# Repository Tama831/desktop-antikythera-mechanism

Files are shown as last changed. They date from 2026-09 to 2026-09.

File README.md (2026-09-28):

# Desktop Antikythera Mechanism — 巡る天の心臓 / Meguru

> A desktop-size descendant of the Antikythera mechanism, with a three-axis tourbillon heart.

2000年前の天文計算機アンティキティラ機構の子孫に、月の秤動・サロス周期・傾く天球、そして
**18.6年の交点歳差 (誤差 +0.18%)** を仕込んだ真・3軸機構。すべて歯数の整数比から。
家庭医 たま × Claude (AI) の共作 (2026-07〜08)。

A three-axis tourbillon descendant of the Antikythera mechanism: lunar libration, Saros cycle,
tilted ecliptic sphere, and the 18.6-year lunar nodal precession (+0.18% error) — all from
integer gear ratios. Co-created by a family physician and Claude (AI).

**▶ 解説サイト / Site**: https://tama831.github.io/desktop-antikythera-mechanism/

## 中身 / Contents
- `meguru_v6.scad` — 全パラメトリック設計 (OpenSCAD)。collide/bite/シェル/engage の検証 PART 込み
- `stl/` — 印刷部品 38ファイル・48個 (Phrozen Sonic Mini 4K 想定・タフレジン推奨)
- `BOM.md` — 部品表・輪列仕様・組立手順
- `mesh-verification.md` — 修正45件の検証履歴 (検査の四点測量の記録)
- `verify_v7.sh` / `stl_solid.py` / `stl_vol.py` — 全数検証の台本 (OpenSCAD Manifold バックエンド・数分)
- `pairwise.sh` / `pairwise.scad` — 総当たり (20剛体・手回し/モーターの2モード)・重力 (支えの有無)・付け替え経路 (モーターの揺りかごを前へ滑らせる掃引) の検査 / `physics_check.py` — トルク・浮き・倒れにくさ (`--tip`) の机上計算
- `stands.scad` — 置き方の触れる比較で選ばなかった案 (A 三つ足 / C 台座ドラム) の記録
- `docs/` — 機構解説・組み立ての書・印刷計画書・隣接台帳 (GitHub Pages)

## 状態 / Status
> ✅ **置き方とモーターの揺りかごまで設計・検証済み (v0.7.3, 2026-09-28)**: アーミラリーの三脚+足輪で立ち (倒れ始める傾き 56°)、モーターは揺りかごを前から滑り込ませてノブの下面の横溝に軸を差す (工具なしで手回しと付け替え)。物理チェックで見つかった組み上がらない箇所も修正済み (v0.7.2)。**実機は未印刷**です。
> Designed and verified through v0.7.3: an armillary-style tripod with a foot ring (tips over only past 56°), and a motor cradle that slides in from the front so the stepper shaft enters a slot under the hand knob (swap between hand and motor without tools). Not yet printed.

設計・検証フェーズ完了。**実機は未印刷** — 実体化の記録は今後ここに追記します。
Design & verification complete; **not yet printed**. Build log will follow.

## この環境にだけ在る前提 / Assumptions
- 検証コマンド (BOM/検証台帳内) は OpenSCAD CLI + Python3 が前提 (`openscad`, `python3` in PATH)
- `verify_v7.sh` は **Manifold バックエンド付きの OpenSCAD** (2025年以降の開発版/リリース) が前提。旧 CGAL 専用版では `--backend` が無い
- 印刷パラメータは光造形 XY 35µm クラス想定。FDM では小歯 (m0.5) と提灯ピン d1.6 の再現が困難です
- 真鍮丸棒 φ3 (60/27.4/9.9mm)・28BYJ-48・M3 ローレットねじ/皿ねじ 等の非印刷部品は BOM.md 参照

## License
MIT

## 訂正 / Correction (2026-09-28)

以前このリポジトリとサイトで交点歳差を「誤差 +0.10%」と掲載していましたが、(a) 比べる相手が天文の実値 (230.05朔望月) でなく設計目標 (228) だったこと、(b) 遊星段がターンテーブルの回転に引っぱられる分 (連成) を計算に入れていなかったことの二点で誤りで、実際は −1.37% でした。v0.7.1 で地下輪列の最終段を 65T に変え、連成込みで +0.18% にしています (mesh-verification.md fix36)。同じ連成のため ESP32 の月時計も 0.59% 遅れていたので補正しました (fix38)。

We previously stated the nodal-precession error as +0.10%. That compared against our design target (228 synodic months) rather than the astronomical value (230.05), and it ignored the epicyclic coupling of the planetary stage; the true error was −1.37%. In v0.7.1 the last under-base stage became 65T, giving +0.18%. The ESP32 lunar clock, which ignored the same coupling, was also corrected.

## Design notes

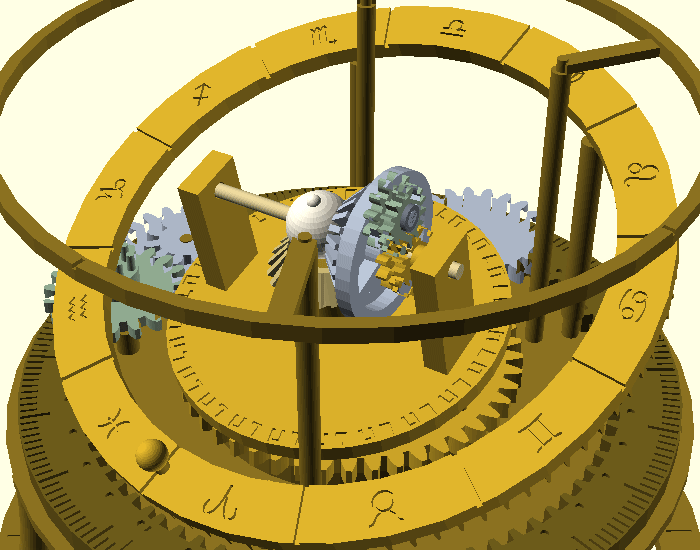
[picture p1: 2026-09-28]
docs/precession_v7.gif

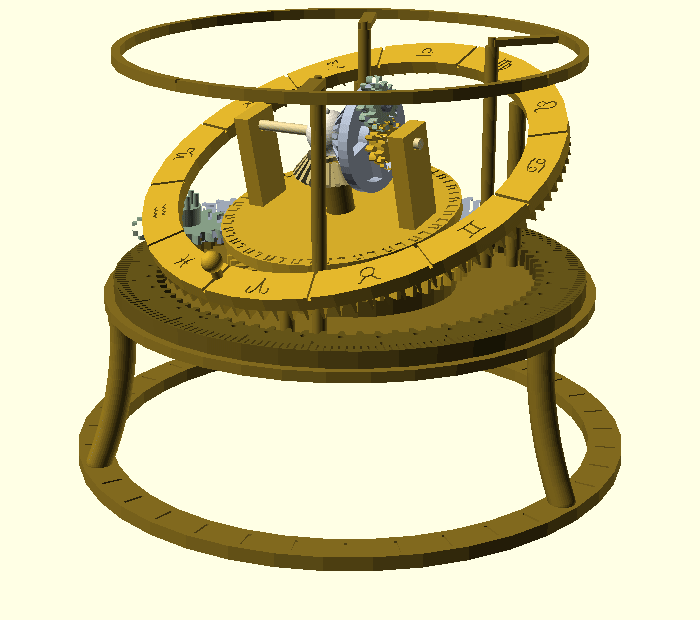
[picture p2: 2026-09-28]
docs/turntable_v7.gif

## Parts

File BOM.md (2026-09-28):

# 巡る天の心臓 v0.7.3 — 部品表と組立ガイド

> アンティキティラ × トゥールビヨン 統合機構 — **真・3軸トゥールビヨン** (2軸+歳差) + 秤動の月 + サロス周期 + 傾く天球 + 自動歳差 + 電動。
> ソース: `meguru_v6.scad` / STL: `stl_v6/` (全38ファイル・シェル+ビルド域検証済) / 動作: `turntable_v7.gif` `precession_v7.gif`
> **訂正 (2026-09-28)**: 以前「交点歳差の誤差 +0.10%」と掲載していましたが、(a) 比べる相手が天文の実値でなく設計目標
> (228朔望月) だった (b) 遊星段の連成を計算に入れていなかった、の二点で誤りで、実際は **−1.37%** でした。
> v0.7.1 で地下輪列の最終段を 65T に変え、連成込みで **+0.18%** (230.45 / 天文 230.05 朔望月) になっています。経緯は mesh-verification.md fix36。
>
> プリンタ想定: Phrozen Sonic Mini 4K (133×75×130mm)・タフレジン。**未印刷 = 実機未検証の設計**です。
> 旧版 BOM (v0.4c) は git 履歴を参照。
>
> ⚠️ **凍結版を印刷する場合のバックポート**: v4 (v0.5) = fix29/29b/30 ✅適用済 (2026-08-15) /
> v0.2.2・v0.3b = fix10/13 に加え fix29系も未適用 — 印刷非推奨

## 印刷部品 (27行・計48個 — 手回しだけなら47個)

| # | 部品 (STL) | 個数 | 系 | 役割 | 印刷メモ |
|---|---|---|---|---|---|
| 1 | base_seg0/1/2 | 3 | 土台 | ベース120°×3 (**fix32: 切り線 az48/168/288**。浅皿23.0・土手・縦シャフト穴・裏スタッド2・**サロス座溝 (fix39)**・**スタッドの肩 (fix41)**・**st1 の腕木 (fix40)**・**面合わせの天球3点支持 (fix45)**・柱・**裏面に隠し刻印「ΜΗΧΑΝΗ ΟΥΡΑΝΟΥ」深0.8**・**脚の位置決め穴3 (縁 r68 — 刻印の外・fix46)**・**揺りかごの受け柱2 (下へ23.4・fix48)**) | 裏スタッドと受け柱がある向きに注意・上面継ぎ板で接合 |
| 2 | splice_plate | 3 | 土台 | ベース継ぎ板 6×8×2 (境界上面 **r23.4-29.4** = 浅皿と土手の間に瞬着) | 平置き |
| 3 | spine | 1 | 歳差 | **背骨一体**: ターンテーブル r20.2+冠環43T+遊星スタッド2 (**肩つき・fix41**)+傾斜柱2 (リブ楕円)+傾斜プレート (**+x 側切り欠き・fix43** — 遊星を下ろせるように)+ボス | **逆さ印刷推奨** (ボス下向き)・柱にサポート |
| 4 | ring46 | 1 | 駆動 | 複合リング (外歯46T+内歯36+上面ピン24+下面ガイド溝) — 下流とピン×冠の心臓駆動を兼ねる | ピン上向き・溝側にサポート薄 |
| 5 | sun_gear | 1 | 駆動 | 太陽12T (中心軸 z9-13 圧入) + **下ハブ d6 (fix41: ターンテーブル上面に載って中心軸ごと受ける)** | ハブ下向き |
| 6 | planet_gear | 2 | 駆動 | 遊星12T (背骨スタッド上フリー回転・(36+12)/2=24 で組立可) | 小物 |
| 7 | stud_cap | **5** | 駆動/秤動/歳差 | スタッド端キャップ (遊星2+E2P+**地下の吊りスタッド2 (fix41)** の抜け止め・瞬着) | 小物 |
| 8 | cage_core | 1 | 心臓 | かごコア (ハブ+台+下面**冠歯24 台形テーパー**+アーム2+E1楕円一体・**台座上面に雷文縁取り 深0.5**) — 旧46Tの跡地に冠歯 | **心臓部品**。冠歯側を上に逆さ印刷 |
| 9 | bevel_sun | 1 | 心臓 | 固定傘24Tマイター (背骨ボス頂部・局所z31 に瞬着 — すきま0.15の接着はめ) | — |
| 10 | inner_frame | 1 | 心臓 | 内かごリング+24Tマイター傘一体+秤動スタッド | — |
| 11 | e2p | 1 | 秤動 | E2楕円+P12T 一体 (スタッド上フリー回転) | 小物 |
| 12 | ret_gear | 1 | 秤動 | 戻りG12T (真鍮軸に瞬着・月球と同体) | 小物 |
| 13 | moon_globe | 1 | 心臓 | 月球 d13+頂クレーター (真鍮軸に瞬着・clocking調整可) | 球にサポート |
| 14 | saros_seg0/1/2 | 3 | サロス | サロスリング120°×3 (内歯74 **fix29/29b改**・223目盛+食マーカー・ダボ接合) | 3種非対称 |
| 15 | saros_idler | 1 | サロス | 中間輪22T+上吊り提灯6ピン (**fix29b: 真ピッチ4.5**) | ピン折れ注意→45° |
| 16 | crown_idler | 1 | 天球 | 2段アイドラ (**fix40: 下段22T z9-13 / 上段11T z13.2-15.8 に上下入れ替え** — サロス環との重なり解消・肩で受ける) | — |
| 17 | st1_carrier | 1 | 天球 | 主輪19T (**fix40: z13.2 へ・腕木の肩で受ける**)+ハブ筒+提灯6ピン d1.8 (**fix37: ピン台座を1.8下げ・ピン先端1.2詰め** — 冠歯90の噛み込み解消) | ハブ筒は縦印刷 |
| 18 | ring_seg0/1/2 | 3 | 天球 | 傾斜天球リング120°×3 (十二宮彫り・太陽玉・冠歯90 **台形 1.3→0.5 (fix37)**・案内溝) | 玉にサポート |
| 19 | horizon_seg0/1/2 | 3 | 天球 | 地平環120°×3 (r64-66.5・z70・分至点マーク) | — |
| 20 | ub_pinionA | 1 | 歳差 | 軸ピニオン**14T** m0.5 (中心軸 z-4.9 圧入・クロッキングA_PH=15°) | 小物・◎向き |
| 21 | ub_w1p1 | **2** | 歳差 | W 64T+P 14T 一体 ×2 (**fix33: 3段化・W1P1/W2P2 共用形状**・吊りスタッド上フリー回転) | 薄物・平置き |
| 22 | ub_w3 | 1 | 歳差 | W3 **65T** (縦シャフト下端圧入・**fix36: 最終段だけ65T で交点歳差を天文値へ**) | 薄物・平置き |
| 23 | ub_lantern | 1 | 歳差 | 提灯キャリア+6ピン垂下 d1.6 (縦シャフト上端・**LNT_PH クロッキング**=ピン1本が機械中心を向く角で接着) | ピン上向き |
| 24 | tripod_leg | 3 | 置き方 | **アーミラリーの三脚 (fix46)**: 外へ反る脚 (r68→77)。上端の座 d8 をベース縁に瞬着 (ピン d4 で位置決め)・下端ピン d3 で足輪へ | 立てて印刷 (高さ47.5)・反りの外側にサポート |
| 25 | foot_ring_seg0/1/2/3 | 4 | 置き方 | 足輪 r72-82 を 90°×4 (目盛り33 — 脚の3ヶ所は抜き)・切り口ダボ d1.6 | 平置き (116×31・4種非対称) |
| 26 | motor_cradle | 1 | 電動 | **揺りかご (fix48)**: 28BYJ-48 を載せる板 (耳のねじは皿もみで板に沈める)。前から水平に差し込み、受け柱2本にローレットねじで下から留める — 上の機械にもノブにも触らずに付け替え | 平置き (58×36×3) |
| 27 | hand_knob | 1 | 駆動/電動 | **ノブ兼カップリング (fix47)**: 中心裏・D カット軽圧入 (fix44)。下面に幅3.1 の横溝 — モーター軸の二面幅が前から滑り込む (先端と仕切りの間は1mm 空け、ノブを押し上げない) | 平置き |

退役: crank_pinion / cage (→cage_core) — クランク系は v0.6b で中心軸入力に一本化 / motor_mount (→motor_cradle) — 28BYJ-48 の実寸 (シャフト偏心8mm) と合っていなかった / coupling (→hand_knob の横溝) — 床まで2.6mm でモーターを下へ抜けなかった (v0.7.3)

## 非印刷部品

| 品 | 寸法/型 | 用途 |
|---|---|---|
| 真鍮丸棒 φ3 | 60mm ×1 | 第2軸 (月球・G を瞬着、腕2+E1スリーブがジャーナル) |
| 真鍮丸棒 φ3 | **27.4mm ×1** | 中心駆動軸 (z-14.4〜13。**下端8mm にヤスリで D カット — 平面を中心から1.0mm まで** (fix44)。太陽+軸ピニオン圧入) |
| 真鍮丸棒 φ3 | **9.9mm ×1** | 歳差縦シャフト (z-3.5〜6.4。W3+提灯圧入・ベース穴がジャーナル) |
| 28BYJ-48 | 5V 版 | 電動駆動 (減速比1/64内蔵・静音) |
| ULN2003 基板 | — | モータードライバ |
| ESP32 or Arduino | 手持ち品 | 制御 (`esp32/meguru_drive/` — **v0.6b: 3:1=12288steps/リング回転**) |
| ローレットねじ M3 | 8mm ×2 | 揺りかごを受け柱へ (下から指で締める。受け柱の下穴 d2.6 — 固ければ M3 タップ) |
| 皿小ねじ M3 + ナット | 8mm ×2 組 | 28BYJ-48 の耳を揺りかごの下面へ (机の上で先に留める。頭は皿もみに沈む) |
| 瞬間接着剤 | — | 継ぎ板・ダボ・月球/G/キャップ・bevel_sun・提灯クロッキング・脚と足輪 |

## 輪列仕様 (v0.6b 決定版)

- **入力 (中心軸)**: 裏の hand_knob or coupling+モーター → 中心軸 → 太陽12T → 遊星12T×2 (歳差キャリア上) → **複合リング46/36** (ω_ring = -ω_axle/3・整数比)
- **下流 (リング46T = 旧かご46Tと同一バンド z9-13・完全無改造)**: サロス 1/5.9 (**fix30: 本体と逆回り=上から時計回り・検品17承認**) / 天球 1/12.391 (1年)
- **心臓部**: リング上面ピン24 × かごコア下面冠歯24 (12°差・1:1・fix27台形テーパー) → 傾いた心臓が回る。第2軸マイター24:24 → 月の自転考証・秤動±28.5° 1うなずき/公転
- **歳差 (第3軸・自動)**: 中心軸 → 地下輪列 (**14T→64T ×2段 + 14T→65T** → 提灯6 → 冠環43T) = **1/695.35** (fix36) → ターンテーブル (背骨ごと) が逆行。遊星段の連成 (ω_軸 = 4ω_tt − 3ω_リング) 込みで **リング 230.45 回で1周** — 月の交点歳差 (6793.5日 = 230.05朔望月) に対し **+0.18%**。ノブを回すだけで3軸すべてが正しい比で巡る。※連成のためリング1回転 = 軸 3.0174 回 (ESP32 はこの値で刻む — fix38)
- 意味付け: リング1回転 = 1朔望月 / 天球1回転 ≈ 1年 / ターンテーブル1回転 ≈ 18.6年
- 描画位相: SIDL 2.3 / SAROSR −0.3 / CIDL −3.2 / ST1 6.2 / RING −1.8 / PLNT 15 / CAGE 7.5 / 地下輪列= mesh_phase() 解析解

## 組立手順 (Stage 順 = 各段で動く)

**Stage 0 「土台を継ぎ、三脚で立たせる」**: base_seg×3 (切り線48/168/288) を合わせ、境界上面 r23.4-29.4 に splice_plate×3 を瞬着 → 足輪4片をダボで継ぐ → ベースを裏返したまま縁の穴3つに tripod_leg×3 を瞬着 → 脚の下ピンに足輪を載せて瞬着 → 起こす
**Stage 1 「地下と背骨」**: 裏: W1P1・W2P2 を各スタッドへ → **軸端キャップ2個を瞬着 (fix41)** → 中心軸に ub_pinionA (z-4.9・A_PH) 圧入 → 縦シャフトに ub_w3 圧入しベース穴へ下から → 表: 提灯を LNT_PH (ピン1本が機械中心向き) で圧入接着 → 背骨 (spine) を浅皿へ → 遊星2 をスタッドに載せキャップ瞬着 → 中心軸を通し太陽12T (z9) 圧入 → ring46 を土手に載せる (溝が土手に乗る) → 中心軸の下端に hand_knob を差す → **裏ノブ: リングが回り、ゆっくりターンテーブルが逆行すれば地下開通**
**Stage 2 「心臓が動く」**: cage_core を背骨ボスへ (冠歯がリングピンに噛む) → bevel_sun をボス頂部に瞬着 (すきま0.15の接着はめ — v0.7-D台帳で表記訂正) → inner_frame → 真鍮軸60mm→月球→G→E2P→キャップ (v0.5 と同手順) → **ノブ: 傾いた心臓が回り月がうなずけば成功**
**Stage 3 「大周期を刻む」**: **saros_seg×3 を座溝へ → saros_idler を上から (提灯ピンを環の歯間へ落とす)** (v0.7.2: 旧順では中間輪の円盤が環の歯の真上0.2にかぶって環が下ろせなかった) → crown_idler・st1_carrier → ring_seg×3 → horizon_seg×3 を柱ピンに瞬着
**Stage 4 「電動化」(任意)**: 机の上で 28BYJ-48 を motor_cradle の下面へ (皿小ねじ+ナット) → ノブの溝を手前へ向け、モーター軸の平らな面を左右へ → 揺りかごを前から水平に差し込む (足輪を越える所だけ2.5mm 持ち上げる) → ローレットねじ2本を指で締める → ESP32+ULN2003 は本体の横。手回しに戻す時はねじを抜いて手前へ引き出すだけ (ノブは付けたまま)

## 印刷後の当たり調整 (設計に織り込み済みの実測項目)

- 土手上端・浅皿: 紙シムで滑り調整 (天球の3点支持は fix45 で面合わせ — 紙シム不要に)
- 提灯×冠歯90・ピン24×冠歯24: 3D幾何残差 (≤7mm³) の歯当たり — 渋ければ歯先を軽く篩う
- 地下輪列: 軸間 +0.25 バックラッシ設計 (最終段は 20.00)。渋い/飛ぶ場合は吊りスタッド接着前に**軸間シムで詰め調整**
- 各圧入 (φ2.85) と瞬着位置の実寸確認 (光造形の収縮は樹脂ロット依存)
- 受け柱の下穴 d2.6: ローレットねじが固ければ M3 タップで先にねじを切る (樹脂を割らないため)

## 残る宿題

- ~~真・3軸トゥールビヨン~~ ✅ 2026-08-14/15 (v0.6a 背骨 + v0.6b 地下輪列 → fix36 で 1/695.35・歳差 +0.18%)
- ~~v4 バックポート (fix29/29b/30)~~ ✅ 2026-08-15
- ~~置き方 (Part B)~~ ✅ 2026-09-28 (触れる比較でたまさんが B を選定 → 三脚+足輪・揺りかご。fix46-48)
- **実印刷**: プリンタは岐阜 — 帰宅の合図待ち 🖨️ (復活チェックリスト: reference_gifu_3d_printer)

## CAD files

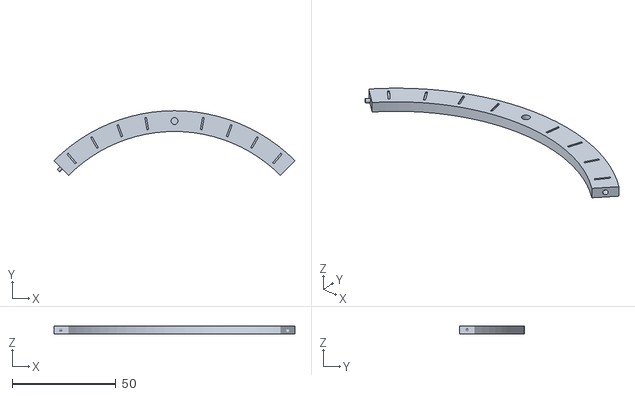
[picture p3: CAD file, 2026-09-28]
stl/foot_ring_seg0.stl
116.0 x 31.1 x 4.00

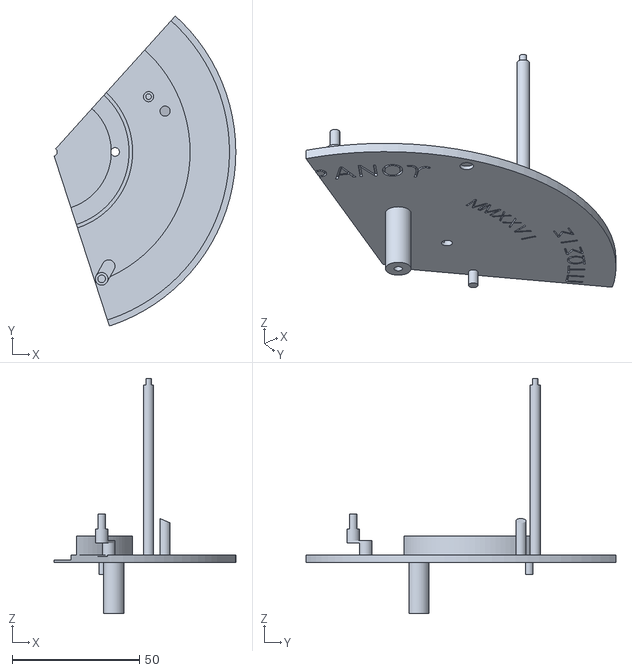
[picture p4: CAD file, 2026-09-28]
stl/base_seg2.stl
71.5 x 121.9 x 92.5

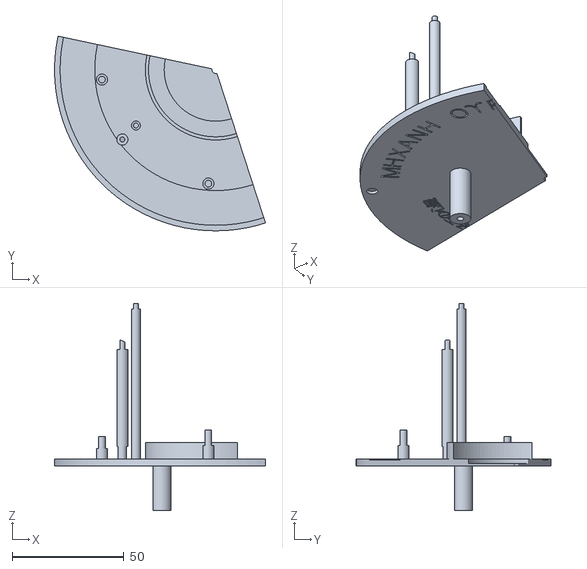
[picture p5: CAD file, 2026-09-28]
stl/base_seg1.stl
94.2 x 87.0 x 92.5

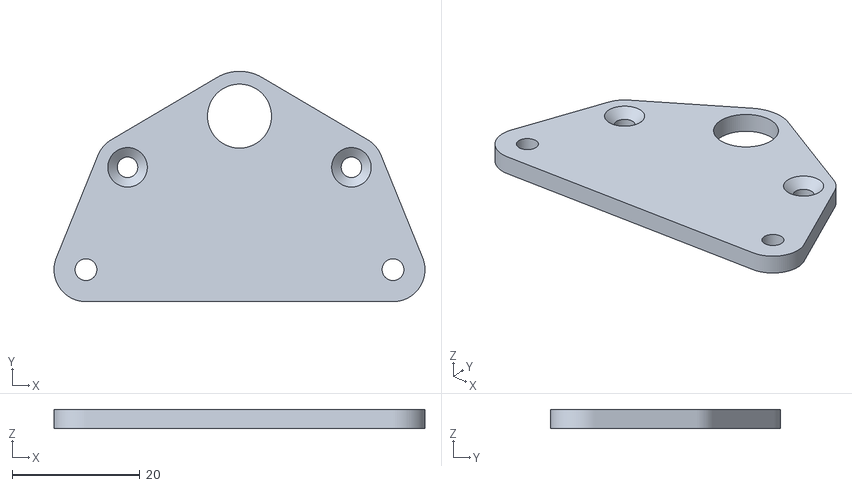
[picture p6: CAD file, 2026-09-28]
stl/motor_cradle.stl
58.0 x 36.0 x 3.00

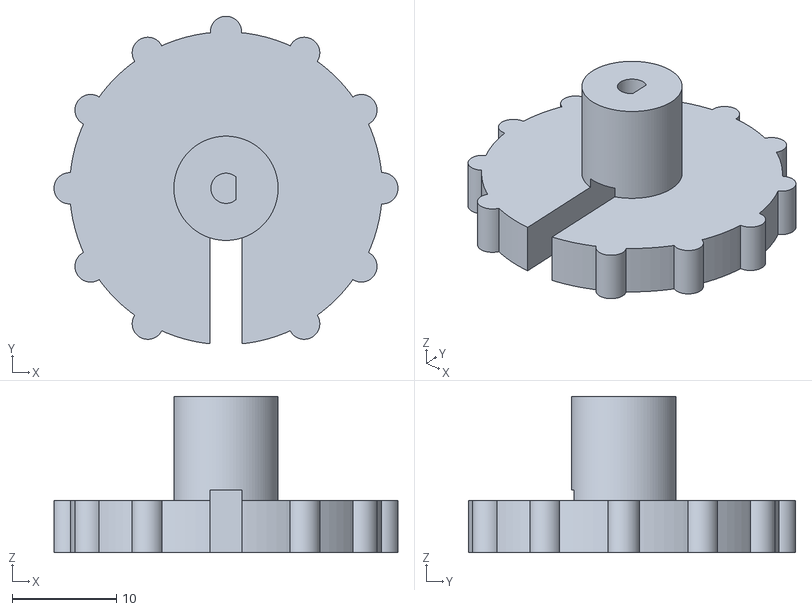
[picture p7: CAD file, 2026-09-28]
stl/hand_knob.stl
33.0 x 31.4 x 15.0

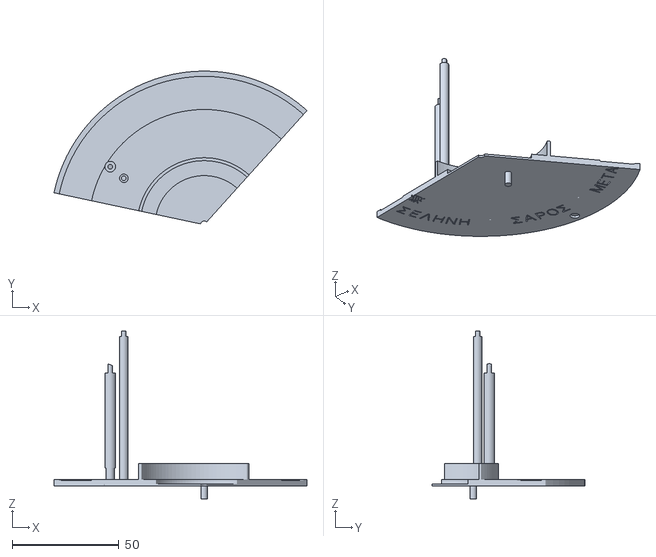
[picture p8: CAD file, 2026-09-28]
stl/base_seg0.stl
118.6 x 71.6 x 78.5

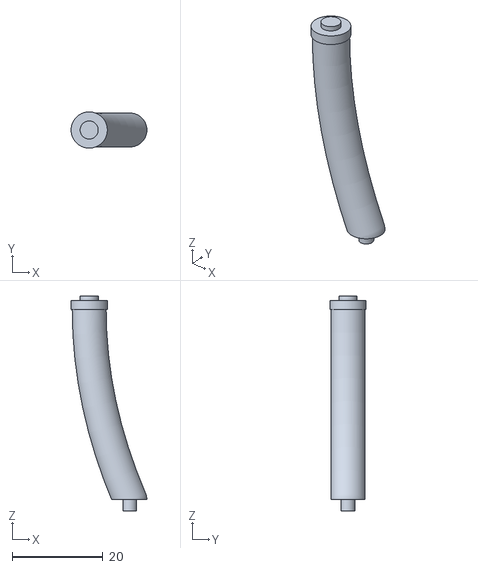
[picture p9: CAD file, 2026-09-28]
stl/tripod_leg.stl
16.7 x 8.00 x 47.5

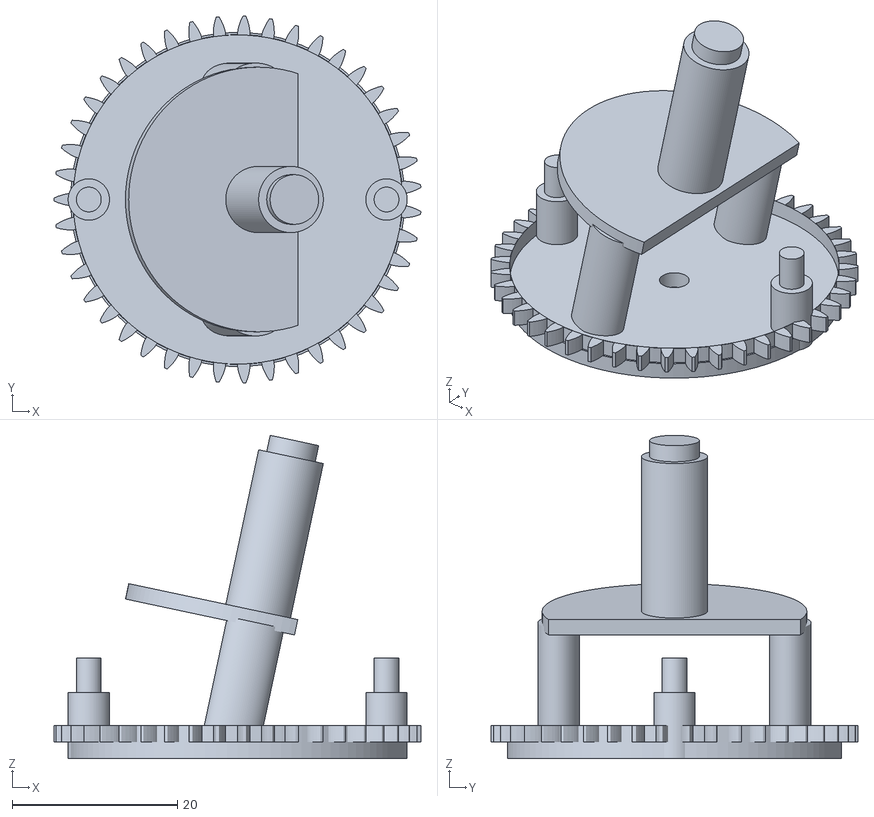
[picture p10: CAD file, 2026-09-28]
stl/spine.stl
44.3 x 44.4 x 39.1

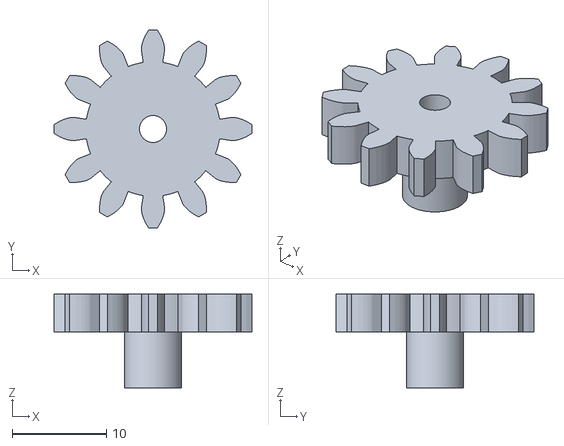
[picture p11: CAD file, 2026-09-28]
stl/sun_gear.stl
21.0 x 21.0 x 9.95

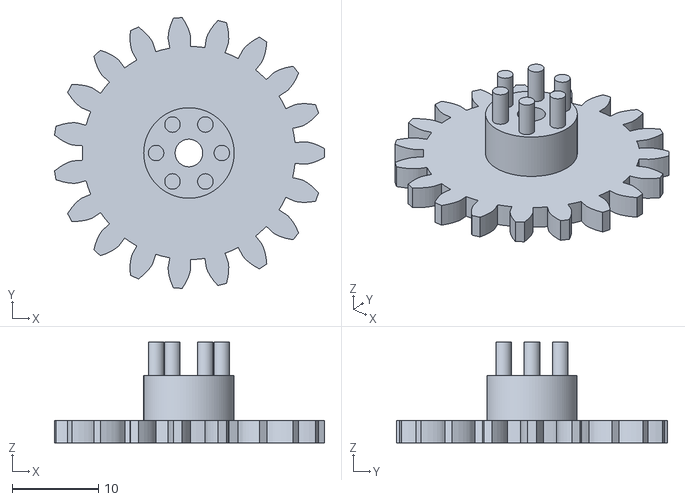
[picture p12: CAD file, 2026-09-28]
stl/st1_carrier.stl
31.4 x 31.5 x 11.7

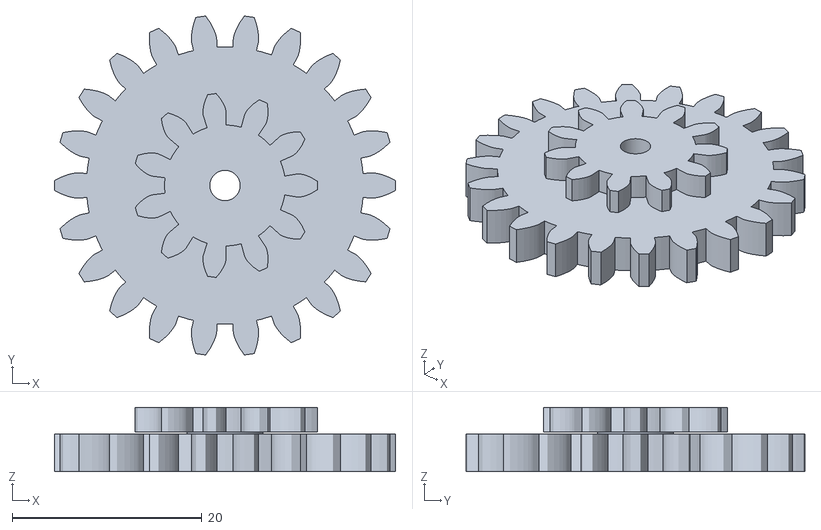
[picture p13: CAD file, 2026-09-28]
stl/crown_idler.stl
36.0 x 35.8 x 6.80

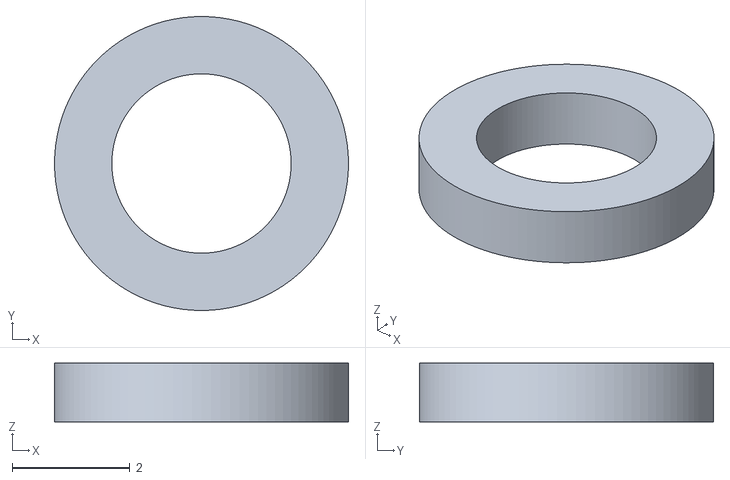
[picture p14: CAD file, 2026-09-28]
stl/stud_cap.stl
5.00 x 5.00 x 1.00

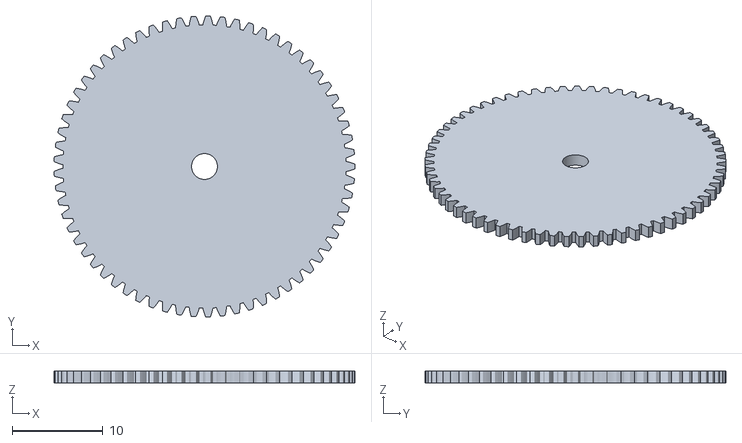
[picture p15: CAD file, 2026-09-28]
stl/ub_w3.stl
33.2 x 33.2 x 1.30

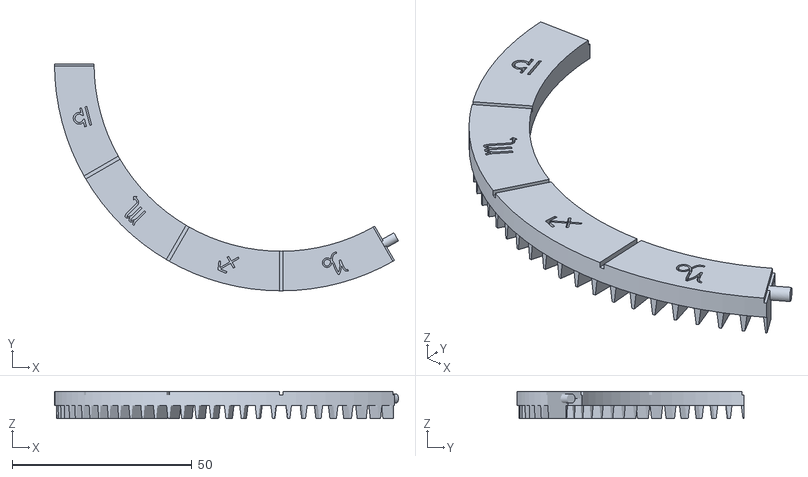
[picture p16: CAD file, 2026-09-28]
stl/ring_seg1.stl
95.6 x 63.0 x 7.60

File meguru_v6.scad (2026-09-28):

// ============================================================
// 巡る天の心臓 v0.6a — 歳差の背骨 (真・3軸トゥールビヨン)
//
// v0.6a 新機構 — 心臓部の回転軸そのものが円錐を描く「歳差」:
//   考証 = 月軌道の昇交点歳差 18.61年 ≈ 230朔望月 → 1/228 (誤差1%・逆行)。傾き12° (5.1°の誇張)。
//   入力は中心の裏ノブ/モーター → 駆動軸 (垂直 z-18..13) → 太陽12T (z9-13)
//   → 遊星12T×2 (ターンテーブル上スタッド r18・az0/180) → 複合リング内歯36
//   → リングが回る (ω_ring = -ω_axle/3)。リング外歯46T が旧かご46Tと同一バンド z9-13 で
//   下流 (サロス/天球輪列) を完全無改造のまま駆動。リング上面ピン24本 (r28.7, z13-16) が
//   かごコア下面の冠歯24 (r25-28) を 12°差のピン×冠で 1:1 駆動 → 傾いた心臓部が回る。
//   心臓部 (かごコア+フレーム+月+秤動系) は「背骨」= ターンテーブル小円盤 (r18.5, z1-3)
//   + 傾斜柱2本 (y±14・リブ楕円断面) + 傾斜プレート (r16) + ボス (d8, 局所z12-31) に乗る。
//   ターンテーブルを回すと傾き方位が回る = 歳差 (v0.6a は手回し, v0.6b で 1/228 自動化)。
//   ※fix25 (設計検算で捕捉): v6-design の「遊星3個・接地スタッド+柱y±8」は不成立 —
//     太陽歯先10.5 > 遊星内到達7.5 で r1.8-28.5 が全周「放射壁」になり、歳差柱がどの半径でも
//     遊星帯 (z9-13) を縦断できない。遊星2個 ((36+12)/2=24 整数 ✓) をターンテーブル
//     (=歳差キャリア) に移し、柱 (az±90) と遊星 (az0/180) を同一回転体で相対固定して解決。
//     キャリア微回転によるリング速度誤差 = (4/3)/228 ≈ 0.6% (歳差→駆動の実結合・表示上無視可)。
// 凍結: v0.5 完成版 = meguru_v4.scad (触らない)。以下 v0.5 までの説明は継承 —
//
// (v0.4a 継承) 秤動の月 (楕円歯車ペア・2軸+脈動)
//
// 第1軸: 外かご (垂直軸・46T 駆動) / 第2軸: 内かごフレーム (水平軸・傘24:24=1.0自転/公転 — v0.5-C)
// v0.4a 新機構 — 月の経度秤動 (libration):
//   焦点軸支の同一楕円歯車ペア (a=6, e=0.25, 軸間 2a=12) + 戻り平歯車 12T×12T (m1, 軸間12)。
//   E1楕円 = かご+x腕に一体 (かご固定=基準) / E2楕円+P12T = フレームリング外面の
//   スタッド (r12) 上でフリー回転 / G12T+月球 = 真鍮軸に接着 (軸ごとジャーナル回転)。
//   伝達関数 F(θ) = 2·atan(((1-e)/(1+e))·tan(θ/2)) — ケプラーの真近点角変換と同型。
//   月の角度 = inner_a − F(inner_a) → 正味自転ゼロ + 首振り ±28.5° (e=0.25)・1うなずき/公転。
//   月は機械中心を向いたまま (同期自転)、垂直回転で位相が1公転1周し、秤動でうなずく。
//   ※誇張の考証: 実月の経度秤動 ±7.9° → 本作 ±28.5° (振幅のみ誇張・v0.2 ±33°と同じ精神)。
//     周期は v0.5-C のマイター化 (フレーム1自転/公転) で実月と同じ1うなずき/公転になった。
//     フレーム=月の額縁自体が1自転/公転 = 月の自転周期の考証もこれで一致。
//   ※v0.3b の差動傘12T (2.5自転/公転・ペア5近似噛み) は本方式で不要になり削除 —
//     近似ペアが消え、噛合は全ペア厳密になった。2軸版の退避先 = meguru_v3_2axis.scad (凍結)。
//   ※真鍮軸は v0.3b の「腕に圧入」から「腕2+E1スリーブ=計3ジャーナルで回転」に変更。
//     月球・G は軸に瞬着 (中央まで圧入摺動できないため。clocking 調整も利く)。
// 段階: v0.4a 秤動 ✓ → v0.4b 傾く天球 ✓ (本ファイル。黄道傾斜23.4°リング+冠76駆動 1/12.39=年周) → v0.4c 印刷準備。
// 外周: サロス減速輪列・黄道リング・電動系は v0.2.2 から不変。
// 1軸完成版 = meguru_ten_no_shinzo.scad (凍結) / 2軸版 = meguru_v3_2axis.scad (凍結)
// ============================================================

PART = "assembly"; // base | bevel_sun | bevel_pinion | cage(旧) | cage_core | inner_frame | moon_globe
                   // | e2p | ret_gear | ell_test | stud_cap
                   // | ring46 | sun_gear | planet_gear | spine   (v0.6a 歳差の背骨)
                   // | pillar_bridge | crank_pinion(退役) | crank_handle(退役)
                   // | saros_seg | saros_idler | zodiac_half | hand_knob (motor_mount/coupling は v0.7.3 で退役)
                   // | assembly | exploded | anim | anim_prec | collide | collide_prec
                   // | mesh_self_pin | mesh_self_moon | mesh_self_e2p | mesh_self_ret | mesh_ell | bite_pair(2-10)

$fn = (PART == "anim" || PART == "anim_prec" || PART == "turntable") ? 40
    : (PART == "collide" || PART == "collide_sun" || PART == "collide_heart" || PART == "collide_sky" || PART == "collide_prec") ? 24 : 96;   // bite_pair は 96 必須 (24だとCGALが退化出力=偽陰性)

// ---------- 共通 ----------
AXLE_D = 3.0; AXLE_FIT = 3.2; AXLE_PRESS = 2.85;
GEAR_H = 4;
M_MAIN = 1.5;
Z_CRANK = 12; Z_CAGE = 46;
CRANK_DIST = M_MAIN*(Z_CRANK+Z_CAGE)/2;   // 43.5

// 第2軸系 (v0.3a ベベル版)
BEV_SUN_T = 24;    // v0.5-C: 30→24 — 1:1マイター化 (フレーム1自転/公転 = 月の自転の考証)
BEV_PIN_T = 24;    // v0.5-C: 15→24 — 比 24/24 = 1.0 (秤動も1うなずき/公転に — 実月と同周期)
BEV_SUN_R = 12;    // 固定傘の外半径
GLOBE_Z  = 43;     // 第2軸高さ (v0.3a-fix2: 月球と固定傘の分離)
INNER_R  = 15;     // 内かごリング半径 (v0.3b: 内径12 — 遊星歯先11.2 が収まる)
INNER_Y  = 14.5;   // リング中心面 (v0.3b: y+ 側の1枚のみ)
// --- 秤動輪列 (v0.4a) — v0.3b の差動傘 12T は削除 (近似ペア5消滅) ---
A_ELL  = 6;        // 楕円歯車 半長径 → 軸間 2a = 12
E_ELL  = 0.25;     // 離心率 → 秤動振幅 ≈ 2e rad = ±28.5° (実月±7.9°の誇張)
Z_ELL  = 16;       // 楕円歯数 (両輪同一・位相0/0.5)
TH_ELL = 2.2;      // 楕円歯車厚
Z_RET  = 12; M_RET = 1.0; TH_RET = 2.2;   // 戻り平歯車 P×G — 軸間 m(12+12)/2 = 12 = 2a (共用)
STUD_R = 2*A_ELL;  // カウンタースタッド半径位置 = 12 (楕円・戻り両ペアの軸間)
RET_X  = 16.4;     // P/G ペアの x 開始 (リング外面16 + 0.4)
ELL_X  = RET_X + TH_RET + 0.3;   // 18.9 — E1/E2 ペアの x 開始
SLV_X  = ELL_X + TH_ELL;         // 21.1 — E1 背後の一体スリーブ開始 (腕面まで)
CAP_X  = SLV_X + 0.3;            // 21.4 — スタッド端・接着キャップ位置
ARM_Y  = 23.5;     // 直立アーム内面 (v0.4a: 22.5→23.5 — 秤動輪列+キャップの逃げ 1.1 確保)

CAGE_R = 35; CAGE_H = 3.5;
H_SAROS = 2.5;     // v0.6a: 4→2.5 — セグ帯 2.5-7.5 (グランド z 再割り当て)
H_CAGE = 16;
BOSS_TOP = 31;     // v0.5-C: 33→31 (45°傘は同じ外径r12でz31まで裾が下がる)。v0.6a ではプレート局所座標
BRIDGE_H = 47;     // クランク軸受け弦腕 (v0.6a: クランク系ごと退避 — 入力は中心軸へ)
CRANK_TOP = 53;

// --- v0.6a 歳差の背骨 ---
PREC_TILT = 12;    // 歳差の傾き (月軌道傾斜5.1°の誇張。クラスタ天井 ≈67.8 < 地平環70 検算済)
PREC_Z  = 7.2;     // ピボット高さ (心臓部フレーム z0 面が乗る空間高さ)。冠歯最下点 13.5 > リング上面 13
PREC_AZ = 0;       // 歳差方位 (v0.6a は手回しパラメータ。anim では誇張スイープ)
TT_R    = 20.2;    // ターンテーブル小円盤 (z1-3)。v0.6b: 18.5→20.2 — 冠環43T (根元19.9-20.25) の座
PIL_Y   = 14;      // 傾斜柱 y±14 (az±90)。内側面 |y|=11.5 > 太陽歯先10.5 / 遊星(az0/180)とはキャリア同体
PLATE_R = 16;      // 傾斜プレート (局所 z10-12)。縁の最下点 13.65 > リング上面 13
Z_SUN = 12; Z_PLNT = 12; Z_RINT = 36;   // 太陽/遊星/リング内歯 (m1.5)。組立条件 (36+12)/2=24 整数 ✓
PLNT_R = M_MAIN*(Z_SUN+Z_PLNT)/2;       // 遊星スタッド半径 = 18
RING46_RATIO = -Z_SUN/Z_RINT;           // ω_ring/ω_axle = -1/3 (キャリア静止時)
PIN_N = 24; PIN_R = 28.7;  // リング上面ピン列 (d2.2, z13-16)。r = 冠ピッチ26.5 の傾斜投影 26.5·cos12+13.4·sin12
CR24_RI = 25; CR24_RO = 28; CR24_TL = 4.6;   // かご下面冠歯24 (ピッチ26.5)
CR24_WR = 4.2; CR24_WT = 1.9;  // 歯幅: 根元4.2→先端1.9 の台形テーパー (fix27 — 傾き射影の方位歪みは
                               // 噛み窓の端 (±48°) で最大2°=1.1mm。歯が浅くしか届かない外方位ほど
                               // すき間が増える形にして、ピンフランク擦り 5.4mm³ を削る)
BANK_RI = 30.0; BANK_RO = 31.4; BANK_TOP = 10.5;  // グランド土手 (リング下面溝 29.7-31.7 の滑り座・紙シム調整)
SUN_PH = 0; PLNT_PH = 15; CAGE_PH = 7.5;  // 描画位相 (bite で追試・調整)

// --- v0.6b 歳差の自動駆動 (地下輪列 2026-08-14 夜) ---
// 上ルートは柱+スタッドの歳差掃引壁 (z3-17, r11-19.5) で不成立 → ベース裏 z-3.9〜-0.5 の平面列。
// 縦シャフト (r24.5, az0) がベースを貫通し、提灯6ピンがターンテーブル上の冠環43Tを回す
M_UB = 0.5;                         // 地下層モジュール
// fix33: 8T/10T は φ3 軸・スタッドに存在できない (歯底円 < 穴半径で胴が消える)。φ3系の最小 ≈13T →
// 「14T→64T ×3段」に再設計。3段で符号も自然に4反転 (最終の提灯×冠環込み) — アイドラ廃止
ZB_A = 14; ZB_W = 64; ZB_P = 14;    // 各段: ピニオン14T → ホイール64T (32/7)。W1P1 / W2P2 の2枚は共用形状
ZB_W3 = 65;                         // fix36: 最終段だけ 65T — 遊星段の連成込みで交点歳差を天文値に合わせる (下の検算参照)
RT_T = 43; M_RT = 1;                // ターンテーブル冠環 43T m1 (ピッチ21.5・z3-5 上乗せ)
LNT_RP2B = M_RT*6/2;                // 提灯ピッチ r3 (6ピン — LANT_PINS はサロス節で後方定義のためリテラル)
PREC_RATIO = pow(ZB_W/ZB_P, 2)*(ZB_W3/ZB_P)*(RT_T/6);   // 軸/ターンテーブル = 695.35
// 遊星段: ω_軸 = 4ω_tt − 3ω_リング、地下輪列: ω_tt = ω_軸/PR (同符号) → 歳差1周 = リング (PR−4)/3 回 (逆行)
//   = 230.45 朔望月 vs 天文 230.05 (交点周期6793.5日) → +0.18%
//   ※fix36 前の「1/684.66・誤差+0.10%」は (a) 天文230でなく設計目標228との比較 (b) 連成の −4 を落としていた。真値は −1.37% だった
AUTO_PREC = 1;                      // 1: pa が ca に従属 (実機通り)。0: 手回し表示 (旧 v0.6a 挙動)
UB_CD  = M_UB*(ZB_P + ZB_W)/2 + 0.25;    // 段軸間 19.75 (+0.25 バックラッシ — W歯先×ピニオン基礎円のマージン0.11確保)
UB_CD3 = M_UB*(ZB_P + ZB_W3)/2 + 0.25;   // 最終段の軸間 20.00
S1_XY = [0, UB_CD];                 // W1P1 スタッド (az90 — スクリューヘッド(0,±26) とは z で棲み分け)
S3_XY = [24.5, 0];                  // 縦シャフト = 冠環ピッチ21.5 + 提灯3 (固定 — 冠環側の幾何で決まる)
// S2 = |S1-S2|=UB_CD・|S2-S3|=UB_CD3 の円交点 (軸から遠い側 — W2 が軸を飲まないように)
UB_D  = norm(S3_XY - S1_XY);
UB_A  = (UB_CD*UB_CD - UB_CD3*UB_CD3 + UB_D*UB_D)/(2*UB_D);
UB_H  = sqrt(UB_CD*UB_CD - UB_A*UB_A);
S2_XY = S1_XY + UB_A*(S3_XY - S1_XY)/UB_D + UB_H*[-(S3_XY[1]-S1_XY[1]), S3_XY[0]-S1_XY[0]]/UB_D;
// 噛合位相の解析解: gear1(位相p1,歯z1) から方位 az の gear2(歯z2) へ「歯↔溝」を渡す
function mesh_phase(p1, z1, z2, az) =
  let (d1 = ((az - p1) % (360/z1) + 360/z1) % (360/z1))       // gear1 の歯ズレ (噛合線基準)
  az + 180 + (0.5 - d1/(360/z1)) * 360/z2;                    // gear2 は溝を向ける (+半ピッチ - 転写)
A_PH  = 15;                                                    // 軸ピニオン (太陽と別クロッキングで圧入)
W1_PH = mesh_phase(A_PH, ZB_A, ZB_W, 90);
W2_PH = mesh_phase(W1_PH, ZB_P, ZB_W, atan2(S2_XY[1]-S1_XY[1], S2_XY[0]-S1_XY[0]));   // P1はW1と同位相(同体)
W3_PH = mesh_phase(W2_PH, ZB_P, ZB_W3, atan2(S3_XY[1]-S2_XY[1], S3_XY[0]-S2_XY[0]));
RT_PH = 180/RT_T;                   // 冠環: pa=0 で az0 (ピン側) に溝
ENGRAVE = 1;                        // v0.7 銘: 案1「考証オマージュ」採用 (2026-08-16 たまさん選定)。0で無刻印・2/3は比較用に残置
LNT_PH = 180 - W3_PH;               // 提灯のクロッキング (組立時接着): ca=0 でピン1本が機械中心を向く

// サロス (v0.2.2 不変)
SAROS_N = 74; SAROS_RP = 55.5; SAROS_RO = 69; SAROS_H = 5;
LANT_PINS = 6; LANT_RP = LANT_PINS*SAROS_RP/SAROS_N;
IDLER_R = SAROS_RP - LANT_RP; Z_IDLER = 22;
LANT_RP2 = LANT_RP;   // fix29b: 真ピッチ4.5へ復帰 — fix19c の0.6縮小が転がり共役を崩し中間位相で
                      // ピン胴×歯フランクが擦っていた (7-11mm³・v0.2以来)。fix19c が避けた2つの干渉は
                      // 歯先短縮 (54.1→54.4・非噛合ピン退避0.15) と セグ壁後退 (56.3→56.8・ピン外縁逃げ0.3) で解決
IDLER_A = 185;   // v0.4b: 240→185 移設 (y-下象限を天球駆動列に明け渡す)
SAROS_RATIO = (Z_CAGE/Z_IDLER)*(LANT_PINS/SAROS_N);
// 旧・固定黄道リング (v0.4b で傾斜天球に発展的解消 — zodiac_half モジュールは退避残置)
ZOD_RI = 44; ZOD_RO = 55; ZOD_H = 4; ZOD_Z = 36;
ZOD_PILLARS = [60, 180, 300];
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

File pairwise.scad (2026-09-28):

// v0.7.2 総当たり検査 (五つ目の網) と重力の確認 (六つ目の網)。v0.7.3 で置き方 (三脚+足輪)・モーター・床を追加
// 総当たり: 全部品を剛体に分け、全ペア (i<j) の交差体積を測る。collide は「回るもの×固定物」、
//   bite は「噛み合う相手」だけを見るので、回るもの同士の非噛合ペアが死角だった
//   (2026-09-28: サロス環 × st1/冠アイドラ の 324/42mm³、環 × ベース板の 2566mm³ がこの死角に6週間いた)。
// 重力 (GRAV=1): 剛体 I を 0.3 下げて、噛み合う相手以外の全剛体と交わるか = 「下で何かが受けている」か。
//   CAD の中の部品は宙に浮いても回るので、支えの有無はこれでしか見えない。
// 使い方: openscad --backend=Manifold -D 'PART="none"' -D I=a -D J=b -D CA=角度 [-D GRAV=1] [-D MOTOR_MODE=1] pairwise.scad
//   16 = 手回しノブ (MOTOR_MODE=0) / カップリング (MOTOR_MODE=1)。18 = 揺りかご+モーター (MOTOR_MODE=1 のときだけ)。19 = 床
include <meguru_v6.scad>
I = 0; J = 1; CA = 0; GRAV = 0;
N_BODY = 20;
// 噛み合う相手・圧入の相手 (重なりが設計どおり — bite/engage で別管理)
PARTNERS = [[3,4],[3,5],[5,9],[8,9],[5,10],[10,11],[11,12],[5,6],[6,7],[4,13],[13,14],[14,15],[2,15],[4,16]];
function is_partner(i, j) = len([for (p = PARTNERS) if ((p[0]==i && p[1]==j) || (p[0]==j && p[1]==i)) 1]) > 0;

module body(i, ca) {
  pae    = PREC_AZ - 3*ca/(PREC_RATIO - 4);
  axle_a = 4*pae - 3*ca;
  w1 = -axle_a*ZB_A/ZB_W + W1_PH;  w2 = -(w1 - W1_PH)*ZB_P/ZB_W + W2_PH;  w3 = -(w2 - W2_PH)*ZB_P/ZB_W3 + W3_PH;
  if (i == 0)  { base(); ub_caps(); }                                                  // 固定 (軸端キャップは瞬着)
  if (i == 1)  translate([0,0,70]) horizon_ring();
  if (i == 2)  rotate([0,0,pae]) spine();
  if (i == 3)  rotate([0,0,pae]) for (a = [0,180]) rotate([0,0,a]) {
                 translate([PLNT_R,0,9]) rotate([0,0, 3*ca - 3*pae - a + PLNT_PH]) planet_gear();
                 translate([PLNT_R,0,13.2]) stud_cap(); }
  if (i == 4)  { translate([0,0,9]) rotate([0,0,axle_a + SUN_PH]) sun_gear();         // 中心軸一式 (太陽・真鍮・ピニオンA — 圧入で一体)
                 translate([0,0,AXLE_BOT]) cylinder(d = AXLE_D, h = 13 - AXLE_BOT);
                 translate([0,0,-4.9]) rotate([0,0,axle_a + A_PH]) ub_pinionA(); }
  if (i == 5)  translate([0,0,9]) rotate([0,0,ca]) ring46();
  if (i == 6)  rotating_heart(ca, pae);
  if (i == 7)  rotate([0,0,pae]) translate([0,0,PREC_Z]) rotate([0,PREC_TILT,0]) translate([0,0,BOSS_TOP]) bevel_sun();
  if (i == 8)  rotate([0,0, -ca*SAROS_RATIO + SAROSR_PH]) for (k = [0:2]) rotate([0,0,k*120]) translate([0,0,H_SAROS]) saros_seg(k);
  if (i == 9)  rotate([0,0,IDLER_A]) translate([IDLER_R,0,H_SAROS]) rotate([0,0, -ca*Z_CAGE/Z_IDLER + SIDL_PH]) saros_idler();
  if (i == 10) translate([CIDL_XY[0], CIDL_XY[1], CIDL_Z]) rotate([0,0, -ca*Z_CAGE/Z_CIDLA + CIDL_PH]) crown_idler();
  if (i == 11) translate([ST1_XY[0], ST1_XY[1], ST1_Z]) rotate([0,0, ca*(Z_CAGE/Z_CIDLA)*(Z_CIDLB/Z_ST1A) + ST1_PH]) st1_carrier();
  if (i == 12) translate([0,0,TR_ZT]) rotate([0,TILT,0]) rotate([0,0, ca*RING_RATIO + RING_PH]) tilt_ring();
  if (i == 13) translate([S1_XY[0], S1_XY[1], -4.9]) rotate([0,0,w1]) ub_w1p1();
  if (i == 14) translate([S2_XY[0], S2_XY[1], -3.6]) rotate([0,0,w2]) ub_w1p1();
  if (i == 15) translate([S3_XY[0], S3_XY[1], 0]) {                                     // 縦シャフト一式 (W3・真鍮・提灯)
                 translate([0,0,-2.3]) rotate([0,0,w3]) ub_w3();
                 translate([0,0,-3.5]) cylinder(d = AXLE_D, h = 9.9);
                 translate([0,0,3.1]) rotate([0,0,w3 + LNT_PH]) ub_lantern(); }
  if (i == 16) translate([0,0,AXLE_BOT - 7]) rotate([0,0,axle_a]) hand_knob();           // ノブ兼カップリング (D カット軽圧入・下面の横溝にモーター軸)
  if (i == 17) { tripod_legs(); foot_ring(); }                                          // 置き方 (脚は座面に瞬着・足輪にピン)
  if (i == 18 && MOTOR_MODE == 1) motor_group(axle_a);                                  // 揺りかご+28BYJ-48+ねじ類 (受け柱に下から留める)
  if (i == 19) translate([0,0,-STAND_H - 5]) cylinder(r = 120, h = 5);                  // 床 (机の天板)
}

// 付け替え経路 (PATH=1・七つ目の網): 揺りかご+モーターを「前へ45 → 上へ2.5 → さらに前へ85」滑らせた掃引体と、残り全部の交差。
//   ローレットねじは先に抜くので掃引に入れない。軸角0 (ノブの溝が前を向き、モーター軸の平らな面が ±x を向く位置) で見る
PATH = 0;
if (PATH == 1) intersection() {
  union() {
    for (seg = [[[0,0,0],[0,-45,0]], [[0,-45,0],[0,-45,2.5]], [[0,-45,2.5],[0,-130,2.5]]])
      for (c = [0:10]) hull() { translate(seg[0]) motor_convex_part(c); translate(seg[1]) motor_convex_part(c); }
  }
  union() {
    for (j = [0:15]) body(j, 0);
    translate([0,0,AXLE_BOT - 7]) hand_knob();            // 溝が前 (-y) を向く角度
    body(17, 0); body(19, 0);
  }
}
module motor_convex_part(c) {   // 揺りかご+モーターを凸な部品に分けたもの (凸なら hull(始点, 終点) = 正確な掃引)
  if (c == 0) translate([0,0,MOTOR_FACE]) linear_extrude(height = 3) hull() {
    for (p = CRADLE_POSTS) translate(p) circle(d = 10);
    for (s = [-1, 1]) translate([s*17.5, -8]) circle(r = 5);
    circle(d = 14);
  }
  if (c == 1) translate([0,-8,MOTOR_FACE - 19]) cylinder(d = 28, h = 19);
  if (c == 2) hull() for (s = [-1, 1]) translate([s*17.5, -8, MOTOR_FACE - 0.8]) cylinder(r = 3.5, h = 0.8);
  if (c == 3) translate([0,0,MOTOR_FACE]) cylinder(d = 9, h = 1.5);
  if (c == 4) translate([0,0,MOTOR_FACE]) cylinder(d = 5, h = 4);
  if (c == 5) translate([0,0,MOTOR_FACE + 4]) intersection() { cylinder(d = 5, h = 6); translate([-1.5,-3,0]) cube([3, 6, 6]); }
  if (c == 6) translate([-7.3, -25, MOTOR_FACE - 18.5]) cube([14.6, 9, 17]);
  if (c == 7) translate([-17.5, -8, CRADLE_TOP - 8]) cylinder(d = 3, h = 8);
  if (c == 8) translate([17.5, -8, CRADLE_TOP - 8]) cylinder(d = 3, h = 8);
  if (c == 9) translate([-17.5, -8, MOTOR_FACE - 3.2]) rotate([0,0,30]) cylinder(d = 6.35, h = 2.4, $fn = 6);
  if (c == 10) translate([17.5, -8, MOTOR_FACE - 3.2]) rotate([0,0,30]) cylinder(d = 6.35, h = 2.4, $fn = 6);
}

if (PATH == 1) { }
else if (GRAV == 0) intersection() { body(I, CA); body(J, CA); }
else if (GRAV == 1) intersection() {
  translate([0,0,-0.3]) body(I, CA);
  union() { for (j = [0:N_BODY-1]) if (j != I && !is_partner(I, j)) body(j, CA); }
}

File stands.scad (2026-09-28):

// Part B「置き方」の触れる比較 (2026-09-28) の記録 — たまさんが B (アーミラリーの三脚+足輪) を選び、正典 meguru_v6.scad へ移した。
// ここに残すのは選ばなかった A 三つ足 / C 台座ドラム と、比較の場面を描き直すための枠だけ。
// B・揺りかご・28BYJ-48 の実体は正典側 (tripod_legs / foot_ring / motor_cradle / motor_28byj48)。
// 使い方: openscad -D 'PART="none"' -D OPT=1..3 [-D MOTOR_MODE=1] -D 'SP="scene"' stands.scad
//   ※本体 meguru_v6.scad は知らない PART 名だと末尾の else で全体組立を描くので、本体には PART="none" を渡す
include <meguru_v6.scad>
SHOW_STAND = 0;   // 正典の組立図が描く B を消し、ここで OPT の案を描く
SP = "scene";
OPT = 2;          // 1=A 三つ足 / 2=B 三脚+足輪 (正典) / 3=C 台座ドラム

// ---------- A 三つ足 ----------
module stand_A() {
  for (a = LEG_AZ) rotate([0,0,a]) translate([64, 0, 0]) {
    translate([0,0,-2]) cylinder(d = 16, h = 2);                                          // 上の座 (ベース下面に接着/ねじ)
    translate([0,0,-STAND_H + 2]) cylinder(d1 = 8, d2 = 11, h = STAND_H - 4);            // 脚 (細くなる円錐)
    translate([0,0,-STAND_H]) cylinder(d1 = 15, d2 = 12, h = 2);                          // 足先の座
  }
}

// ---------- B アーミラリーの三脚 + 足輪 (正典) ----------
module stand_B() { tripod_legs(); foot_ring(); }

// ---------- C 台座ドラム ----------
module stand_C() {
  difference() {
    union() {
      translate([0,0,-STAND_H]) difference() { cylinder(r = 72, h = STAND_H); translate([0,0,-1]) cylinder(r = 69, h = STAND_H + 2); }
      translate([0,0,-STAND_H]) difference() { cylinder(r = 75, h = 3); translate([0,0,-1]) cylinder(r = 69, h = 5); }   // 裾
      translate([0,0,-6]) difference() { cylinder(r = 72, h = 6); translate([0,0,-1]) cylinder(r = 66, h = 8); }          // 上縁 (ベースの継ぎ目も抱く)
    }
    for (a = LEG_AZ) rotate([0,0,a]) {                                                    // アーチ窓 ×3 (手回しノブへ手が届く/中が見える)
      translate([60, -22, -STAND_H + 6]) cube([20, 44, 14]);
      translate([60, 0, -STAND_H + 20]) rotate([0,90,0]) cylinder(r = 22, h = 20);
    }
  }
}
module stand_C_parts() {   // 中の電子部品 (見た目の目安): ULN2003 基板 35×32 / ESP32 開発ボード 52×28
  color("#2f6b3a") translate([-52, -16, -STAND_H]) cube([32, 35, 14]);
  color("#1d1d1d") translate([18, -55, -STAND_H]) rotate([0,0,35]) cube([52, 28, 11]);   // 四隅 r≤65.6 (壁 r69 の内)・モーターの配線カバーから7離す
}

module stand_only(opt) { if (opt == 1) stand_A(); if (opt == 2) stand_B(); if (opt == 3) stand_C(); }
module stand(opt) { if (opt == 1) color("#8a7020") stand_A(); if (opt == 2) color("#8a7020") stand_B(); if (opt == 3) { color("#8a7020") stand_C(); stand_C_parts(); } }

module scene(opt, ca) {   // モーター/手回しは -D MOTOR_MODE で切り替える
  assembly(explode = 0, ca = ca);
  stand(opt);
  color("#e9e4d8", 0.35) translate([0,0,-STAND_H - 2]) cylinder(r = 110, h = 2);          // 床 (目安)
}

if (SP == "scene") scene(OPT, 25);
if (SP == "turn") rotate([0,0,$t*360]) scene(OPT, $t*360);
if (SP == "check_stand")   // 置き方 × 機械 (ベースとの接着面の薄膜は別勘定)
  intersection() { stand_only(OPT); union() { base(); ub_caps(); motor_group(); translate([0,0,AXLE_BOT - 7]) hand_knob(); } }
if (SP == "stand_only") stand_only(OPT);

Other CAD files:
stl/foot_ring_seg1.stl
stl/foot_ring_seg2.stl
stl/foot_ring_seg3.stl
stl/ring_seg2.stl
stl/bevel_sun.stl
stl/cage_core.stl
stl/e2p.stl
stl/horizon_seg0.stl
stl/horizon_seg1.stl
stl/horizon_seg2.stl
stl/inner_frame.stl
stl/moon_globe.stl
stl/planet_gear.stl
stl/ret_gear.stl
stl/ring46.stl
stl/ring_seg0.stl
stl/saros_idler.stl
stl/saros_seg0.stl
stl/saros_seg1.stl
stl/saros_seg2.stl
stl/splice_plate.stl
stl/ub_lantern.stl
stl/ub_pinionA.stl
stl/ub_w1p1.stl

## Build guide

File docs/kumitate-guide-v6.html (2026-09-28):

# 巡る天の心臓 — 組み立ての書

哲学はひとつ:「各段で必ず動く」。動かないまま次へ進まない

## はじめる前に

印刷: stl_v6/ 全38ファイル (Phrozen Sonic Mini 4K・タフレジン)。プリンタは長期休眠明け → 復活チェックリスト (nFEP膜・LCD露光・Z軸・レジン新調) を先に。
道具: 瞬間接着剤 / 紙 (シム用) / ピンバイス (穴さらい) / ニッパ・ヤスリ / 真鍮φ3棒 60mm・27.4mm・9.9mm の3本 / (電動にする時) M3 ローレットねじ×8mm ×2・M3 皿小ねじ×8mm+ナット ×2
心構え: 圧入がきつい時は無理せず穴をさらう。渋い噛み合いは「歯当たり調整」(BOM末尾) が織り込み済み

exploded

全部品の分解図 (手回しの姿) — 印刷部品47個と真鍮軸3本

## Stage 0 「土台を継ぎ、三脚で立たせる」

stage0

部品: base_seg0/1/2 (×3)・splice_plate (×3)・tripod_leg (×3)・foot_ring_seg0/1/2/3

1. 3枚のセグを平面で突き合わせる (切り線 az48/168/288 — 裏スタッドの向きで判別)
2. 境界の上面 r23.4〜29.4 帯 (浅皿の外・土手の内) に splice_plate を瞬着 ×3ヶ所
3. 裏返して隠し刻印「ΜΗΧΑΝΗ ΟΥΡΑΝΟΥ」を眺めてニヤリとする (必須工程)
4. 足輪: foot_ring_seg×4 を平らな机の上で継ぐ (切り口のダボ d1.6 を隣の穴へ差して瞬着)
5. ベースを裏返したまま、縁の小穴3つ (刻印のさらに外側) に tripod_leg×3 の上ピンを差して瞬着 — 脚は外へ反る向き
6. 上を向いた脚の下ピン3本に足輪を載せて瞬着 (目盛りが抜けている3ヶ所が脚の位置) → そっと起こす

✅ 動作確認: 足輪で机に立ってガタつかない・浅皿と土手の円が真円に繋がっている・ベースの下 (高さ48mm) に指が入る

## Stage 1 「地下と背骨」

stage1

部品: ub_w1p1 (×2)・ub_pinionA・ub_w3・ub_lantern・spine・planet_gear (×2)・stud_cap (×2)・sun_gear・ring46・hand_knob・真鍮27.4mm+9.9mm

1. 裏側: W1P1・W2P2 を吊りスタッドへ (P面が下向き=ベースから遠い側) → スタッド端に軸端キャップを瞬着 (抜け落ち防止)
2. 縦シャフト9.9mmの下端に ub_w3 を圧入 → ベース穴 (r24.5) へ下から通す
3. 表に出た上端へ ub_lantern を圧入・ピン1本が機械中心を向く角度で瞬着 (LNT_PHクロッキング)
4. spine (背骨) をそっと浅皿へ — 冠環43Tが提灯ピンと噛む
5. 遊星2個をスタッドに載せ stud_cap を瞬着。中心軸27.4mm (下端8mm をヤスリで D カット) を通し、裏から ub_pinionA・表の z9 に sun_gear を圧入
6. ring46 を土手に載せる (下面の溝が土手の上に乗る)
7. ベースの下から、中心軸の下端 (D カット) に hand_knob を差す (軽圧入・抜き差しできる)

✅ 動作確認: 裏ノブを回す → リングが軽く回り、ターンテーブルがごくゆっくり逆方向に回れば地下開通 (リング約230回転でターンテーブル1周 — 少し回して冠環の歯が1枚動けば正常)

渋い時: 地下輪列は遊び大きめ設計。逆に飛ぶ/滑る時は吊りスタッド接着前に軸間へ紙シムを入れて詰める

## Stage 2 「心臓が動く」

stage2

部品: cage_core・bevel_sun・inner_frame・moon_globe・ret_gear・e2p・stud_cap・真鍮60mm

1. cage_core を背骨のボスへ (雷文の面が上・下面の冠歯24がリング上面のピン24と噛む)
2. bevel_sun をボス頂部の段に圧入・瞬着 (回らない部品)
3. inner_frame を第2軸位置へ。真鍮60mmを −x腕 → 月球 → フレームハブ → G (ret_gear) → E1スリーブ → +x腕 の順で通す
4. 月球 (クレーター上向き基準) と G を瞬着。e2p をスタッドに載せキャップ瞬着

✅ 動作確認: ノブを回す → 12°傾いた心臓が回り、月の額縁が縦に回り、月が公転ごとに1回うなずけば成功。ゆっくり回し続けると傾きの向きも徐々に変わる (歳差)

## Stage 3 「大周期を刻む」

stage3

部品: saros_idler・saros_seg0/1/2・crown_idler・st1_carrier・ring_seg0/1/2・horizon_seg0/1/2

1. saros_seg×3 をダボ接合し、ベースの座溝へ落とす → saros_idler を上からスタッドへ (提灯ピンを環の歯間へ・22T をリング46に噛ませる)。順番注意: 中間輪が先だと円盤が環の歯にかぶって環が入らない
2. crown_idler (22T を下に) をスタッドへ・st1_carrier を腕木のスタッドへ — どちらも肩の上に載る
3. ring_seg×3 をダボ接合 → 支柱ピン2本を下面溝に、内縁下面を方位20°の座へ (3点とも天面がリングの傾きに合わせてあるので、そのまま載る)
4. horizon_seg×3 を柱3本の先端ピンに瞬着 — 地平環が全てを囲む

✅ 動作確認: リング6回転でサロスが1周 (時計回り)・12回転で太陽玉が黄道を1周。玉が地平環の腕の下 (すき間2.8mm) をすり抜けるのを見届ける

## Stage 4 「電動化」(任意)

stage4

stage4 slide-in

揺りかごは手前から水平に差し込む (赤い矢印)。ノブの下面の溝にモーター軸が入る

部品: motor_cradle・28BYJ-48・ULN2003・ESP32・ローレットねじ M3×8 (×2)・皿小ねじ M3×8+ナット (×2) — ノブはそのまま (下面の溝がカップリングを兼ねる)

1. (机の上で) 28BYJ-48 の耳を motor_cradle の下面に当て、皿小ねじを上から通してナットで留める — 頭は板に沈み、シャフトが板の大穴から上へ出る
2. ノブを指で回して下面の溝を手前に向ける。モーター軸も指で回して、平らな面を左右に向けておく
3. 揺りかごを手前から水平に差し込む — 足輪を越える所だけ少し (2.5mm) 持ち上げ、あとは板の上面を受け柱の下端に沿わせて奥へ。モーター軸がノブの溝に入り、溝の奥で止まる
4. ローレットねじ2本を下から指で締める (受け柱の下穴 d2.6 にねじが自分で溝を切る — 初回だけ固い)
5. ESP32 + ULN2003 を本体の横に置いて配線し、esp32/meguru_drive/ を書き込む (secrets.h は example から)

手回しに戻す時: ローレットねじ2本を抜き、揺りかごを手前へ引き出すだけ。ノブも上の機械も触らない (床まで2.6mm しかないので、下へは抜かない)

✅ 動作確認: lunar モードで1朔望月=リング1回転をリアルタイム刻み (約12359 steps・206.4秒/step — 遊星段の連成込み)。放っておくだけで月も年も食も歳差も、正しい速さで巡り続ける

## 困った時 (当たり調整早見)

症状 | 処方
ターンテーブルがガタつく | 浅皿・滑り座に紙シム
天球リングが傾き方向に落ちる | 滑り座 (az20) の座面に紙シム
提灯まわりが渋い | 歯先を軽くヤスリで篩う (設計上の残差は最大0.3mm³まで — v0.7.1)
地下輪列が滑る/飛ぶ | 吊りスタッド接着前に軸間シムで詰め
圧入が入らない | ピンバイスで穴さらい (光造形の収縮はロット依存)
モーター軸がノブの溝に入らない | ノブの溝を手前へ、モーター軸の平らな面を左右へ向け直す。それでもきつければ溝の壁を軽くヤスリで
ローレットねじが固すぎる | M3 タップで受け柱の下穴にねじを切ってから締める (樹脂を割らないため)

巡る天の心臓 v0.7.3 組み立ての書 (2026-08-16 初版 / 2026-09-28 物理チェック・置き方 (三脚+足輪)・揺りかご反映) — 詳細仕様: BOM.md / 機構解説: mechanism-explainer-v6.html
たまさん × Claude 共作 — 楽しい共作、急がない 🌙

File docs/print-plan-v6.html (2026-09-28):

# 巡る天の心臓 — 印刷計画書

Phrozen Sonic Mini 4K (133×75×130) × タフレジン・レイヤー0.05mm 想定 — 岐阜の日は「開封→即印刷」

## ぜんぶでどのくらい?

48個印刷部品 (38ファイル)

約179cc実体樹脂 (+サポート≈215cc)

約250gレジン消費 (500g瓶1本で足りる)

18プレートプレート数

約21時間機械時間合計

¥1,100〜1,600樹脂コスト概算

時間はプレートの最大高さ×約2.8分/mm (露光2.5s+リフト) の概算。実測でキャリブレーションを。v0.7.3 で置き方 (三脚+足輪 25.3cc) と揺りかご (4.3cc) が加わり、旧モーター台・カップリングは退役した。

## プレート割り (推奨順 — 小さく検証してから大物へ)

# | のせる物 | 最大高 | 時間目安 | ねらい

P1 | 小物一式: ring46・ub_w1p1×2・ub_w3・sun・planet×2・bevel_sun・crown_idler・saros_idler(45°)・e2p・ret・ub_pinionA・ub_lantern・stud_cap×5・splice×3 | ~10mm | ~30分 | 復活直後のキャリブレーション兼ね。歯の出方・圧入穴の寸法をここで検品 (載り切らなければ2枚に)
P2 | 中背もの: st1_carrier・hand_knob・moon_globe(サポート)・inner_frame・motor_cradle | 30mm | ~1.4h | P1の寸法検品が通ってから。ノブ下面の横溝 (幅3.1) にモーター軸が通るかもここで
P3 | 心臓と背骨: cage_core(冠歯上向き)・spine(逆さ・柱サポート) | 39mm | ~1.8h | 主役2部品を1枚で。雷文と冠歯の出方を検品
P4-6 | saros_seg0 / 1 / 2 (各1枚) | 5mm | 各~14分 | 低くて速い。223目盛の彫りを検品
P7-8 | ring_seg0 / 1 (各1枚) | 7.6mm | 各~21分 | 十二宮の彫りを検品
P9 | ring_seg2 (太陽玉つき・玉にサポート) | 15.6mm | ~44分 | —
P10-12 | horizon_seg0 / 1 / 2 (各1枚) | 3mm | 各~8分 | 薄物の反り注意 — 底面ベタ付け
P13-14 | 足輪 foot_ring_seg 2片ずつ (116×31 を向かい合わせて) | 4mm | 各~11分 | 薄物・底面ベタ付け。目盛りの彫りを検品
P15 | 三脚 tripod_leg×3 (立てて・反りの外側にサポート) | 47.5mm | ~2.2h | 細長い — 倒れないようサポートを密に
P16 | base_seg0 | 78.5mm | ~3.7h | 柱が伸びる長丁場。裏スタッドにサポート
P17-18 | base_seg1 / base_seg2 (各1枚・揺りかごの受け柱つき) | 92.5mm | 各~4.3h | 最後の大物2枚。刻印面はプレート側 — 文字はそのまま出る。夜に仕掛けるのが吉

プレートに載るかの根拠: 全部品は回転考慮でビルド域 133×75×130 に収まることを検証済み (base_seg は要回転)。 実スライサーでの配置時、ここの組を崩しても高さの近い者同士でまとめれば時間は同等。

## 部品別データ (実測: STLから算出)

部品 | 個数 | 樹脂/個 | 底面 (mm) | 高さ | 姿勢・サポート
base_seg0/1/2 | 3 | 16.6-17.8cc | 108×72 | 78.5-92.5 | 表を上・柱そのまま上へ。裏スタッドと受け柱 (seg1/2) に軽サポート
cage_core | 1 | 17.1cc | 70×70 | 36 | 冠歯上向き=逆さ・腕とE1にサポート
saros_seg 各 | 3 | 8.4cc | 120×42 | 5 | 平置き・彫り面上
spine | 1 | 5.9cc | 44×44 | 39 | 逆さ (ボス下向き…プレート側)・傾斜柱2本にサポート
ring_seg 各 | 3 | 4.8-5.0cc | 109×38 | 7.6-15.6 | 上面上・seg2の太陽玉にサポート
foot_ring_seg 各 | 4 | 4.8cc | 116×31 | 4 | 平置き・目盛り面上・2片で1枚
ring46 | 1 | 5.1cc | 72×72 | 6.6 | ピン上向き・下面溝は小さくサポート不要見込み
hand_knob / motor_cradle / crown_idler / saros_idler | 各1 | 3.6-4.3cc | 32〜58×36 | 3-15 | ノブは握り面を下 (横溝は上向きで検品しやすい)・saros_idler はピン折れ防止で45°
tripod_leg | 3 | 2.0cc | 17×8 | 47.5 | 立てて (上の座を下)・反りの外側にサポート
inner_frame / st1_carrier | 各1 | 2.1-3.2cc | ~31角 | 12-30 | st1 はハブ筒を縦に
horizon_seg 各 | 3 | 1.2cc | ~116×36 | 3 | ベタ付け平置き (反り注意)
小物 (傘・月・遊星×2・太陽・E2P・G・地下輪列5・キャップ×5・継ぎ板×3) | 20 | 計~9.5cc | — | 1-14 | 月球のみサポート・歯車は◎向き平置き

## 岐阜の日のチェックリスト

順 | やること
0 | プリンタ復活チェック (nFEP膜・LCD露光テスト・Z軸・タフレジン新調500g) — reference_gifu_3d_printer の手順
1 | 露光キャリブレーション (付属テストか XP2 バリデータ) — タフレジンの適正露光を確定
2 | P1 小物プレートを印刷 → 圧入穴φ2.85に真鍮3.0が入るか・歯形の出・ピンの立ちを検品。ダメなら露光/穴径を調整して再戦
3 | P2〜P15 を順に (すきま時間で回せる短いプレート群。三脚だけ2時間強)
4 | base_seg 3枚 (各4時間前後 — 夜に仕掛けるのが吉)
5 | 組み立ては「組み立ての書」(kumitate-guide-v6.html) の Stage 0 から

覚え書き: 光造形の寸法はレジンロット・露光で±0.05〜0.1mm動く。φ2.85圧入と提灯まわりが渋いのは想定内 — ピンバイスと紙シムで「当たり調整」する前提の設計 (BOM末尾)。

巡る天の心臓 v0.7.3 印刷計画書 (2026-08-16 初版 / 2026-09-28 置き方・揺りかご反映) — 実測データ: stl_v6/ 全38ファイルから算出
たまさん × Claude 共作 — 印刷の日を、楽しみに 🖨️

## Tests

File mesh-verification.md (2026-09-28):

# 噛合検証表 — 巡る天の心臓 (2026-08-11)

> たまさんの指摘「噛み合うべきところ以外の衝突がないか / 噛み合うべきところの衝突は適切か」を受けた3層検証の記録。

---

# v0.4a 秤動の月 (meguru_v4.scad, 2026-08-11 夜)

## 検証体系 (3層 + 位相 + シェル)

| 層 | 何を検べる | 方法 | 結果 |
|---|---|---|---|
| A. 非噛合ペア | 回転部×固定部 (**真鍮軸も回転体に計上** — v0.4aで検査対象拡大) | 交差体積 8角度 | ✅ 8/8 ゼロ |
| B. 不適切接触 | 歯vs軸空間 self 4種 + E1歯底×E2 16角度 + G歯底×P 8角度 | 交差 | ✅ 全ゼロ |
| C. 噛合の適切さ | 軸間・噛み帯・食い込み | 数値検算+体積計測 | ✅ 下表 |
| 位相 | **組立座標系**での E1×E2P / G×P 干渉 (`PART="bite_asm"`) | 12角度 (inner_a 0–330°) | ✅ 全ゼロ |
| シェル | 全印刷部品の STL 連結成分 = 1 (歯浮き検出) | union-find 解析 | ✅ 10部品全て 1 |

## C. 噛合ペア数値表 (v0.4a)

| # | ペア | 軸間: 実装 / 理論 | 噛み帯・クリアランス | 判定 |
|---|---|---|---|---|
| 1 | クランク12T × 外かご46T (m1.5) | 43.5 / 43.5 | 歯先-歯底 0.375 (r_d 修正後) | ✅ |
| 2 | 外かご46T × 中間輪22T (m1.5) | 51.0 / 51.0 | 0.375 | ✅ |
| 3 | 提灯6ピン × サロス内歯74 | 55.5 = リングピッチ半径 | 3mm | ✅ |
| 4 | 固定傘30T × フレーム傘15T | ピッチ円錐共有 63.43°/26.57° | 接触母線 t=8〜13.4 | ✅ |
| 6 | E1楕円 × E2楕円 (焦点軸支・位相0/0.5) | 12 = 2a (構成的に厳密) | 噛み帯 4.4mm³ が全8角度一定・食い込み 0 | ✅ |
| 7 | P12T × G12T (m1.0) | 12 = m(12+12)/2 | 0.25 | ✅ |
| 旧5 | 固定傘 × 月球傘12T (近似噛み) | — | **v0.4a で機構ごと削除 — 近似ペア解消** | 解消 |

## 修正履歴 (v0.4a 分)

10. **インボリュート r_d = max(r_p−1.25m, 0.98·r_b) の二重欠陥** (v0.2 以来の潜在。Claude 自己検出 1件目):
    (a) 小歯数で歯が歯底円盤から浮く — crank_pinion STL が13シェル (歯12枚が 0.05–0.08mm 宙吊り)、
    (b) 歯底円盤が標準デデンダムを侵食し**相手歯先と 0.2–0.79mm 干渉** (クランク12T×かご46T で最大 0.79mm = 印刷したら噛み渋り確実)。
    GIF では見えず、collide は回転体×固定体のみ検査するため回転体同士のこのペアは死角だった。
    → r_d = r_p−1.25m に戻し、基礎円下は放射直線フランクで歯元まで延長。STL シェル数=1 検査を機械化。
    **⚠️ 凍結版 v0.2.2 / v0.3b の全 STL に遡及 — 印刷前にこの修正のバックポート必須**
11. `sun2()` 未定義モジュール呼び出し (fix8 混入の死にコード — OpenSCAD は警告のみで黙って無視) と、
    fix9 一体化後も assembly() に残っていた幻の bevel_pinion 重複描画 (リング内に逆向き傘・印刷部品には無関係) を除去
12. 楕円歯車の台形歯が法線≠動径のズレで歯底輪郭から浮く (e2p 14シェル) → 歯基部を −1.4 まで埋め込み (機能寸法は −1.05 のまま)

## 検品記録 (v0.4a 出荷後)

- **検品10「楕円歯車ペアがガタガタに見える」→ シロ判定** (9戦9勝の後、初のシロ。追試 2026-08-12):
  歯位置の数値検査 = 角度誤差 Δθ≤0.004°・隣接歯間隔 2.302〜2.305mm (曲率由来の正常範囲)・E2 単体レンダは端正。
  見え方の正体は3要素の合成 — (a) **E2楕円と P12T が同軸スタック**の部品で、シルエットに両層の歯が混ざる
  (b) 楕円歯は**曲線法線向き**に生えるため場所により傾いて見える (転がり接触として正しい姿勢)
  (c) **GIF のワゴンホイール効果** — 72フレーム版は E2P の歯送りが最大 0.74枚/フレームで歯飛びに見える。
  → 対策: 144f/24fps の `libration_v4_smooth.gif` を追加 (歯送り半減で滑らかに見える)
- **検品11「月は軸に入ったまま揺れるのか」→ 機構説明**: 揺れの実体は**軸そのものの正逆微回転**。
  月球+G12T+真鍮軸は瞬着で一体の剛体、腕2箇所+E1スリーブの**3ジャーナルの中で回転自由度だけ**を持つ。
  軸方向スライドは G↔リング面 0.4 / 球↔傘端 0.65 の突き当てで制限、傾き・首振り (軸線の変位) はゼロ。
  時計のテンプが天真ごと正逆に振れるのと同じ構造 (v0.3b の「固定軸+月フリー回転」から反転した設計)。
  色分け説明図 = `PART="axle_explain"` → render_v4_axle_explain.png

---

# v0.4b 傾く天球 (2026-08-12)

## 機構
黄道傾斜 23.4° の天球リング (r52-63・十二宮刻み・太陽玉) が傾斜軸まわりに回転。
駆動: かご46 → 2段アイドラ12T×12T → 45T+提灯6ピン → **冠歯76** (本家アンティキティラ式・v0.3冠廃案の敗者復活)。
比 = (46/45)·(6/76) = **1/12.39** — 天球1回転 = 12.39朔望月 ≈ 1年 (実際 12.368、誤差 0.16% ≈ 3.6日/年)。
リングは傾斜軸まわりの回転体なので占有空間が回転不変 — 干渉検証が静的に落ちる (動くのは太陽玉のみ)。
支持 = 非対称3点: 上がり側2本は溝ピン式支柱 (radial 拘束)、下がり側1本は滑り座 (冠歯が z10-14 までスイープするためピン式不成立)。

## 検証 (v0.4b 追加分)
| 検査 | 内容 | 結果 |
|---|---|---|
| collide_sun 8方位 | 天球リング+太陽玉 (回転) × 固定群 | ✅ 8/8 ゼロ |
| collide_sky 4角度 | 天球系+駆動列 × 固定群 | ✅ 4/4 ゼロ |
| collide 全体 8角度 | 全回転体 (心臓部+天球系) × 固定群 | ✅ 8/8 ゼロ |
| シェル | tilt_ring / base / st1_carrier / crown_idler | ✅ 全て 1 |
| C層 (機上検算) | 冠噛み深さ3.2 / st1-サロス内縁0.74 / 支柱-冠歯0.5-2.7 / リング最低-サロス2.3 ほか13項目 | ✅ ALL OK |

## 修正履歴 (v0.4b 分)

13. **ブリッジ弦腕が v0.3a 以来 90°ズレ** (Claude 自己検出2件目): 配置の `rotate([0,0,-90])` が余計で、腕先端は
    (-64, 20.5) を向いておりクランク軸 (43.5, 0) の上受けは**事実上存在していなかった**。腕は fixed 側なので
    collide では検出されず、傾斜リングがその空間を通って発覚。真鍮φ3片持ちのたわみ検算 (横力1Nで0.08mm) を
    根拠に**上受け廃止を正式設計に** — pillar_bridge は退避 (復活手順コメント付き)。
14. **傾斜の「深さずり込み」を初期検算が無視**: rotate_Y では深さ z が水平位置に混じる (Δ=z·sin23.4°)。
    これにより (a) リング内縁下角がクランク軸に0.7食い込み → 内縁50→52、(b) 冠歯先が下がり側で z10・半径48.9まで
    沈み込み支柱・スタッドを直撃 → 支柱の非対称化 (溝ピン2+滑り座1)・スタッド h18、(c) 垂直ピン×傾斜溝の
    斜行 0.67 → 溝幅 3.2→4.0。教訓: **傾斜体の干渉は「上面基準の投影」でなく最深部の角で検算する**。
15. サロス中間輪を 240°→185° に移設 (y-下象限を天球駆動列に明け渡す)。機能不変 (中間輪の方位は自由)。

## 既知の設計注記 (v0.4b)
- 滑り座 (az20・r45) の座面高さ 15.3 は印刷後に紙シムで当たり調整 (サロス滑り座と同じ文化)
- 十二宮目盛りはリングと共に回る「天球」演出 (本家は目盛り固定・指針回転 — 誇張の精神で天球化)。固定の「地平環」追加は v0.5 候補
- リング φ126 — 印刷は 120°×3 分割 (サロス式ダボ、v0.4c 印刷準備で分割線を入れる)

## 既知の設計注記 (v0.4a)

- 秤動振幅 ±28.5° (e=0.25) は実月 ±7.9° の誇張。周期は公転1回に2うなずき (実月は1回) — 合わせるにはフレーム比 2.0→1.0 か楕円 2:1 化 (v0.4b+ の選択肢)
- 楕円歯も台形近似 — 印刷後の当たり調整前提は従来通り
- 月球・G12T は真鍮軸に瞬着 (中央まで圧入摺動できないため。clocking 調整可)。E2P はスタッド+端キャップ瞬着で保持。軸は腕2+E1スリーブの3ジャーナルで回転 (v0.3b の圧入から変更)

---

# v0.3b の記録 (凍結 — 以下は旧版)

## 検証体系 (3層)

| 層 | 何を検べる | 方法 | 結果 |
|---|---|---|---|
| A. 非噛合ペア | 回転部×固定部が触れない | 交差体積計算 (8角度) | ✅ 8/8 ゼロ |
| B. 不適切接触 | 歯が軸・相手本体に食い込まない | 部品×軸空間の交差 + 固定物リスト完全化 | ✅ 2部品クリア (歯向き誤り2件を修正済) |
| C. 噛合の適切さ | 軸間距離・噛み帯が理論値通り | 下表の数値検算 | ✅ 4ペア一致 / 1ペア近似 (注記) |

## C. 噛合ペア数値表

| # | ペア | 軸間: 実装 / 理論 | 噛み帯の重なり | 判定 |
|---|---|---|---|---|
| 1 | クランク12T × 外かご46T (m1.5) | 43.5 / (18+69)/2 = 43.5 | z12-16 ↔ z12-16 (完全一致) | ✅ |
| 2 | 外かご46T × 中間輪22T (m1.5) | 51.0 / (69+33)/2 = 51.0 | z12-16 ↔ z12-16 (完全一致) | ✅ |
| 3 | 提灯6ピン × サロス内歯74 | 噛み半径 51+4.5 = 55.5 = リングピッチ半径 | z6-10 ↔ z4-9 (3mm) | ✅ |
| 4 | 固定傘30T × フレーム傘15T | ピッチ円錐共有: apex(0,0,43)・63.43°/26.57° (比2.0) | 接触母線 t=8〜13.4 上で歯が重なる | ✅ 正設計 |
| 5 | 固定傘30T × 月球傘12T (差動) | 同じ傘に比2.5で噛む → 厳密円錐は21.8°/68.2°で**不整合** | 歯先同士の近似接触 | ⚠️ **意図的近似** — 樹脂・低速・軽負荷の提灯精神。印刷後に噛み深さ実測、渋ければ12T側の歯を篩う |

## 修正履歴 (この検証で見つかった不適切接触)

5. **両傘ピニオンの内外が逆** (たまさん指摘8件目) — 太端が中心側・細端が外側の逆向き配置 (fix3 から)。細端=apex 向きに反転修正
6. **フレームのハブスリーブが傘の細端領域を覆い被さり+傘とフレームの結合矛盾** (たまさん指摘9件目) — スリーブ廃止・15T 傘をフレームに一体化 (太端ハブがリング直結)
7. **歯がピッチ面の外に全高盛りで相手本体に食い込み** — 歯底円錐を新設し、歯をピッチ面を挟んで半々 (addendum/dedendum) に。歯先と相手歯底のクリアランス 0.3mm

1. **両傘ピニオンの歯の向きが誤り** (たまさん指摘6件目) — 歯が母線と逆向きに生え、**軸に食い込む方向**だった (15T: 116.6°→63.7° / 12T: 111.8°→60.5° に修正)
2. **月球の軸穴が傘ハブ奥まで貫通していなかった** — 軸が中実部を貫く状態 (bore 延長で修正)
3. **検査の固定物リストに第2軸真鍮棒が抜けていた** — 歯vs軸の検出漏れの原因 (追加済)
4. 圧入穴 (φ2.85 < 軸φ3) は**意図的な締まり嵌め** — 検査では圧入部を偽検出しないよう検査棒径を区別

## 既知の設計注記

- ペア5の近似は v0.4 で「12T専用の第2傘面を固定傘の裏面に切る」正設計化オプションあり
- 全歯形は台形近似 (インボリュート/グリーソンではない) — 樹脂低速用途の意図的簡略。印刷後の当たり調整前提

---

# 検品12「新しいギアがめり込んでる！」対応 (2026-08-13 進行中)

**判定: 大当たり (12戦11勝1シロ)。** bite_pair 検査 (6ペアの交差体積・$fn=96 必須 — 24はCGAL退化で偽陰性) を新設して掘ったところ、めり込みは実在し、しかも v0.2 以来の実バグ群まで発掘された。

## 確定した修正 (fix16-20)
- **fix16 描画位相の導入**: 全歯車ペアに位相定数 (CRANK_PH 等)。歴代バージョンは位相なしで描画しており、クランク×かご36mm³・サロス67mm³等のめり込みがレンダに常在していた (機構ではなく描画の噓)。位相は解析式 `ψ+180−(360/zb)(0.5+(ψ−θa)za/360)` + bite スイープで決定
- **fix17 45T帯の引越し**: z16.2-20.2 はかご台座+アーム根本が全周掃く帯で駆動輪が住めない (回転体同士=collideの死角)。45Tを空き帯 z9.2-11.8 (サロス9とかご12の間) へ、ピンはハブ筒で立ち上げ
- **fix18 冠歯丈 4.6→3.6**: 冠歯先が az-28 で z11.5 まで沈み45Tと0.3かぶり
- **fix19 サロス提灯3連 (v0.2以来の実バグ)**: (a)下フランジが内歯歯先に5.2mmめり込み→上吊り構造に反転 (b)歯幅2.0>溝2.2でピンが物理的に入らない→歯1.6/ピンd2.0 (c)ピン外縁がセグ本体内周に0.33食い込み→ピン円0.6縮小
- **fix20 噛合点の深さずり込み補正**: fix14の教訓 (x'=xl·cT+zl·sT) を冠噛合点の計算で再発させていた — 2.3mmずれたピン円が歯列に恒常食い込み。実効深さzl=-5.8で補正し噛合方位を-72°へ (45T回避も兼ねる)

## 未了 (次の区切りで)
- PAIR3 恒常2.5mm³: 内歯×提灯は非噛合ピン (±60°) が歯先円に突入する — 退避条件 51+0.5·r_L+r_p≤53.3 → r_L=2.6/d1.8 案 (掛かり1.2、印刷後調整前提) の適用と検証
- PAIR6 恒常6.4mm³: 場所未特定 (クラスタ解析まで)
- 全ペア合格後: collide 全系再検証 + シェル + レンダ/GIF再出力 (現行GIFはめり込み描画のまま)

## 検品12 完了 (2026-08-13 夜)

- **fix21** 冠歯幅 1.8→1.5: 提灯ピッチの局所不整合 0.4 を溝余裕 0.8 で吸収。ハブ z24.6・ピン z24.6-28.8
- **fix19d** サロス歯丈 3.0→2.2: 非噛合ピン (±60°) の歯先円退避と噛み掛かり1.8を両立
- **fix22 サロス中間輪の回転符号が v0.2 以来逆** (位相保存式 Σzᵢdθᵢ=0 で確定): idler は −46/22·ca、
  連動してサロスリングも +SAROS_RATIO·ca に反転 (提灯×内歯のペア内では対称歯形ゆえ整合して見えていた)
- **最終位相**: CRANK 15 / SIDL 2.3 / SAROSR −0.3 / CIDL 2.5 / ST1 2.0 / RING −2.0
- **回転整合 (ca=0/30/57)**: PAIR1/2/4/5/7 = 全て 0.000 ✓ / PAIR3 ≤1.25・PAIR6 ≤4.0 (水平ピン円×傾斜歯列の
  3D幾何残差 — 原理的にゼロ不可・印刷後の歯当たり調整で吸収、と注記して合格)
- **再検証**: collide 8/8 ✅ / collide_sun 4方位 ✅ / collide_sky 2角度 ✅ / シェル全部品 1 ✅
- レンダ・GIF 差し替え: rotation_v4b.gif (全景)・drivetrain_v4b.gif (駆動列側) — めり込み描画は解消

---

# 検品13「薄緑のギアが大きくて中心と被り、サロスが隠れる」対応 (2026-08-13, fix23)

**判定: デザイン実害としてクロ** (物理干渉はゼロだったが、45T は φ70.5 でかご46Tと平面かぶり17.9mm・サロスリングの23% (83°) を上空から覆っていた — 目盛りが読めないのは実害)。

## fix23 天球駆動列の小径化再設計
- 旧: かご46 → アイドラ12×12 → **45T**+提灯6 → 冠76 (1/12.39)
- 新: かご46 → **2段アイドラ22T/11T** → **19T**+提灯6 → **冠90** = (46/22)(11/19)(6/90) = **1/12.391** (誤差0.19%)
- 効果: 主輪 φ70.5→φ31.5、かごとの平面かぶり **17.9mm→ゼロ** (内端37.7 > かご歯先36)、サロス被覆 **83°→34°**
- 冠噛合方位 -72→-65 (N90でピン円縮小→st1半径が外に出るのを相殺、サロスクリア0.52)
- 道中の追加修正: 22Tアイドラ歯先×st1ハブの0.75食い込み → ハブ2段化 (22T帯 d8.6 / 上部 d10.5)
- 位相再確定: CIDL -3.2 / ST1 6.2 / RING -1.8。回転整合 (0/30/57): PAIR4=0.000 / PAIR5≤0.28 / PAIR6≤6.5
  (PAIR6 は N90 化でピン円曲率差が増え 3D残差 1.9→6.1mm³ — 印刷後の歯当たり調整で吸収、と注記)
- 再検証: collide 8/8 ✅ / collide_sun 3方位 ✅ / collide_sky 2角度 ✅ / シェル全部品1 ✅
- STL 差し替え: crown_idler / st1_carrier / ring_seg0-2 (冠90歯)。turntable_v4c.gif 再録

---

# 検品14「クランクが空中に浮いてる・裏から動力を入れては？」対応 (2026-08-13, fix24)

**判定: 採用 (デザイン改善)。** 上空ハンドルは v0.2「リング上空が空いている」前提の設計で、天球リングが覆った
今は (a) 回しにくい (b) fix13 の上受け退避で「支えのない浮いた軸」が丸見え — 論理が逆転していた。

- **fix24 動力入力の裏面一本化**: crank_handle 退避 (復活手順コメント付き)。手回しは裏面の **hand_knob**
  (握り円盤 d30+ローレット+差し込み筒) — モーター用 coupling と同じ d3.25 抜き差し式で差し替え。
  真鍮クランク軸 73→40mm (z-18〜18)。ベース穴13mm+ピニオンで実質全長支持となり片持ち問題も消滅。
- 「完全中央 (0,0) から入れない理由」: 中心は固定ボスの背骨 — サロス滑り座と固定傘30T (第2軸の転がり支点)
  が住んでおり、回転入力を通せない。オフセット入力は本家アンティキティラ (側面ノブ) と同じ作法。
- 検証: collide 4角度 + collide_sun 2方位 スモーク ✅ (軸短縮は安全側・回転体に変化なし)。
  あわせて検品14の質問を受けた**緑ギア再検証**: PAIR2/3/7=0.000, PAIR4=0.001, PAIR5=0.15, PAIR6=6.1 (既知3D残差),
  E2P bite_asm 3角度 ✅ — めり込みなし。
- STL: hand_knob.stl 追加 / crank_handle.stl 削除。turntable_v4d.gif 再録

---

# v0.5-A サロス223刻印+十二宮シンボル (2026-08-13)

- サロスリング: **223朔望月の目盛** (10毎に長刻み) + **食マーカー38点** (i%6==0 の疑似配置 — 本家グリフの
  実配置考証ではないと明記)。223は素数で3等分不可 → セグ3種化 (75/74/74目盛、合計223を機械検算)
- 天球リング: 十二宮の**星座記号 ♈..♓ を text() (Apple Symbols) で深さ0.9彫り** — 12記号のレンダ検証済み
- 注記: サロスの回転比 1/5.9 は誇張のまま — 「223の環」は考証オマージュ (1目盛=1朔望月の実周期表示ではない)
- 検証: 全セグ シェル1 ✅ / collide+sun スモーク ✅ (上面彫りのみ=安全側)。STL: saros_seg0/1/2 (旧 _x3 廃止)・ring_seg0/1/2 差し替え

---

# v0.5-B 地平環 (2026-08-13)

- **傾いた天球を囲む固定の水平環** (r64-66.5・t3・z70) + 柱3本 (az30/150/215・r43.5・d4・h70先端ピン)。
  4方位マーク = 分至点 (牡羊/蟹/天秤/山羊点) の読み取り基準。まさにアーミラリー天球儀の地平環
- 幾何検算11項目 ALL OK: 柱は天球内縁下角投影46.1と冠歯スイープ48.9の内側 r43.5 / 腕z70は太陽玉頂 (最高72.1) と
  radial 棲み分け (環64 vs 玉60) / 環内縁64 vs 天球投影max63
- φ133 は一枚だとビルド奥行75超 → **120°×3分割** (切り線 90/210/330 = 腕回避、円周ダボ d1.6/2.0)
- 道中の事故2件: (a) 環t2にd2ダボ穴が上下貫通し輪切り分離 → t3化 (b) 穴起点が切り面の0.7°内側で**密閉空洞**
  になりシェル2 → 切り面の外から掘り開口。教訓: **盲穴は「開口面を貫いて」掘る**
- 検証: 全セグ シェル1 ✅ / collide_sun 6方位+180 ✅ (環+柱は fixed に計上) / collide 4角度 ✅

---

# v0.5-C 秤動の考証合わせ + v0.5-D ESP32 (2026-08-13)

## v0.5-C: 傘 30:15 → 24:24 マイター化 (フレーム1自転/公転)
- 2案比較の結果採用: 楕円2:1化は秤動周波数が意図方向に動かず部品も複雑化。マイター化は
  **月の額縁 (フレーム) 自体が1自転/公転になり「月の自転周期」の考証も同時に手に入る**
- 秤動: inner_a = ca となり **1うなずき/公転 (実月と同周期)** に。振幅±28.5°は誇張のまま
- 幾何: 45°/45° 対称ペア (apex共有 z43)。ピッチ r7.5-12、root=ピッチ−1.35法線、歯先+1.05 (相手rootと0.3クリア)。
  BOSS_TOP 33→31 (45°傘は同径で裾が低い)。フレーム傘ハブ r12.5 でリング内周12へ0.5重ね
- 道中の事故2件: (a) マイター歯がroot円錐から0.04浮き (25シェル) → 0.15食い込ませ
  (b) add=ded=0.9+食い込ませで**歯先が相手rootに0.15めり込む設計ミス** (collide 8角度全滅で捕捉)
  → 旧傘の流儀 (root−1.35/歯先+1.05/クリア0.3) に統一。教訓: **すき間はaddendumとdedendumの差で作る**
- 検証: collide 8/8 ✅ / B層self 4種 ✅ / bite_asm 4角度 ✅ / シェル1 ✅。libration_v5c.gif 再録 (1うなずき)

## v0.5-D: ESP32 駆動スケッチ (esp32/meguru_drive/)
- 28BYJ-48 ハーフステップ駆動。ステップ数は分数 (46/12=23/6) のまま保持し累積誤差ゼロ
- **lunar モード (既定)**: かご1回転=1朔望月をリアルタイムで刻む月時計 (162.5秒/ステップ・
  ステップ間コイル解放で省電力)。demo = かご1rpm / stop
- HA 連携: MQTT Discovery で switch/select 自動登録 (Gifu VM103 Mosquitto 前提)。secrets.h 方式
- 実機検証は通電時 (岐阜) — コードレビューのみの状態と明記

---

# v0.6a 歳差の背骨 (meguru_v6.scad, 2026-08-14)

## fix25: 「遊星3個・接地スタッド」は放射壁 — 設計検算で着工前に捕捉

v6-design.md 確定トポロジ (遊星3個をグランドスタッド r18 に接地・傾斜柱 y±8) は**幾何学的に不成立**:
- 太陽12T (m1.5) 歯先 r10.5 / 遊星の内側到達 = 18−10.5 = **7.5 < 10.5** → 遊星帯 (z9-13) は
  **r1.8〜28.5 が全周ふさがる「放射壁」**。歳差柱は全方位を掃くので、どの半径でも遊星帯を縦断できない
  (y±8 は太陽に食い込み、外に逃げても遊星セクタに当たり、リング/土手/サロス壁で外周も閉じる)
- **解決: 遊星2個 ((36+12)/2=24 整数 ✓・180°対称) をターンテーブル=歳差キャリアに載せ替え**。
  柱 (az±90・y±14) と遊星 (az0/180) が同一回転体になり相対固定 → 永久に非干渉。
  副作用: キャリア回転がリング速度に (1+Zs/Zr)/228 ≈ **0.6%** 結合 (歳差→駆動の実結合・物理的に本物)
- 教訓: **遊星段は「中心を空ける」が「半径方向の通路」は全部ふさぐ**。回る支持構造が遊星帯を
  貫通する設計では、支持構造と遊星を同一キャリアに載せて相対静止させるのが一般解

## fix26: 内歯シェーパーの半ピッチ位相 (2枚ラック問題)

- 内歯36 = 「46T外形 − offset(0.25)·gear2d(36) − circle(25.5)」のシェーパー切り近似。
  素朴に切ると PAIR9 (遊星×内歯) が**全角度で正面衝突**
- 原因: 偶数歯の遊星は太陽側 (az180) と リング側 (az0) の**両面が「溝」**になる (歯は15°+30k)。
  2枚のラック間を転がる歯車と同じで、内歯側は az0 に「歯」を差し出す必要がある
  → シェーパーを**半ピッチ (180/36 = 5°) 回して**内歯の歯を az0 に配置して解決
- 教訓: 太陽-遊星-内歯の3者位相は「遊星の両面が溝 ↔ 相手両者が歯」。外歯ペアの位相合わせを
  内歯にそのまま流用すると半ピッチずれる

## 検査の検査 (v0.6a 道中)

- 太陽の圧入穴 (bore 2.85) × 中心軸 (d3.0) は**意図した締め代** — v0.5 クランクピニオンと同じく
  「軸と圧入歯車は同一剛体」として collide の固定側軸を z8.5 で止めて除外
- 軸先端面 z9 と太陽底面 z9 の共平面が **厚みゼロの退化シート** (bbox z[9.00,9.00]・96tri) として
  STL に出力され "empty" 判定を偽らせた → 0.5 逃がしで回避。教訓: **共平面接触は 0.5 逃がすか体積で判定**

## グランド z 再割り当て (設計書どおり)

| 帯 | v0.5 | v0.6a |
|---|---|---|
| サロスセグ | 4-9 | **2.5-7.5** (H_SAROS 2.5) |
| 46T (旧かご→複合リング) | 12-16 | **9-13** (下面溝×土手滑り座 r30-31.4) |
| サロスidler 22T | 12-16 | 9-13 (提灯ピンはセグ追随 3.7-7.9) |
| 冠idler / st1 19T | 9.2-16 | 6.2-13 (st1 太ハブ+3 — 天球提灯ピンは z22.8-26.1 を維持) |
| 空いた z13+ 中心 | 固定ボス | **歳差系 (ピン×冠 z13-17・傾斜プレート・傾いた心臓部)** |

## 新噛合ペア (bite_pair 8-10)

| # | ペア | 位相 | 判定 |
|---|---|---|---|
| 8 | 太陽12T × 遊星12T | PLNT_PH=15 (外歯・溝を向ける) | ✅ 10/10 角度 (周期5°を全掃引) |
| 9 | 遊星12T × リング内歯36 | 内歯シェーパー半ピッチ回し (fix26) | (本文末尾の検証まとめ参照) |
| 10 | リング上面ピン24 × かご冠歯24 (12°差 1:1) | CAGE_PH=7.5 | (同上) |

## fix27: ピン×冠の射影歪み — 冠歯テーパー化 (検品16「地平環ぶつからない?」の追試から連鎖発見)

- PAIR10 (リング上面ピン24 × かご冠歯24) が全角度⚠️ → 体積実測 **5.4mm³・z14-16・|y|≤21.4 (方位±48°)**
- 原因: 傾き12°の冠歯列を水平ピン円に射影すると cos12° の楕円圧縮で**噛み窓の端ほど歯の見かけ方位がズレる**
  (±30°で1.1mm、±55°で2.0mm)。24ピン全周噛みは天球冠 (6ピン・狭窓・残差6.1mm³受容) より窓が広く暴れが拡大
- 対策: **冠歯を台形テーパー** (根元4.2 → 先端1.9、hull による傾斜フランク) + **ピン短縮 h3→2.6** (z13-15.6)。
  歯が浅くしか届かない外方位ほど、すき間が自動的に増える幾何 — 残差は印刷後の歯当たり調整で吸収する方針
- 教訓: **傾き越しの全周ピン×冠は「窓の端の射影歪み」で必ず擦る**。窓を絞る (ピン短縮) + 端で逃げる (テーパー) のセット

## fix28: 遊星スタッド × 浅皿の壁 (collide_prec 初陣の戦果)

- 歳差スイープ PREC 0/45 ⚠️ → 体積実測 **4.75mm³・z1-3・|y|max14.2** = 遊星スタッド (r18・外縁19.5) が
  浅皿の壁 (r18.9) に 0.6mm めり込み。通常 collide では背骨が固定側にいて評価されないペア —
  **歳差スイープが初めて背骨×ベースを衝突判定した**ことで捕捉
- 対策: 浅皿 r18.9 → **19.9**。ターンテーブルの調芯は元々中心軸ジャーナル (bore3.4×真鍮3.0) が担うので実害なし
- 教訓: 回転体の集合が変わる新検査は「今まで同じ側にいて評価されなかったペア」を初めて照らす。
  検査を増やした直後の⚠️はまず新規照射ペアを疑う

## fix29: サロス提灯×内歯74 の中間位相クラッシュ — v0.2以来の潜伏バグ (広角走査の戦果)

- PAIR3@90 で **7.401mm³** (z=ピン帯全域)。凍結版 v4 で同条件を追試 → **7.401mm³ 完全一致 = v0.2以来の潜伏**。
  従来の検査は少数角度 (ピンがほぼ整数ピッチに乗る位相) しか踏んでおらず、ca=90 = **3.136ピッチ目**という
  「中間位相」を初めて踏んで発現
- 原因: 内歯74の台形歯 (先端1.6/根元3.0) はピッチ円での歯間 2.30 vs ピン径 2.0 → **遊び±0.15**。
  提灯 (ラタン) 式の正しい共役はサイクロイド逃げが要るのに直線フランクなので、中間位相で必ず擦る
- 対策: 歯幅 **1.2/2.4** に絞る (ピッチ円歯間 2.81・遊び±0.4)。歯先円 54.1 は不変 (fix19d の非噛合ピン退避条件は維持)
- **⚠️ 凍結版 meguru_v4.scad へ印刷前バックポート必須** (fix10/13 と同列 — NEXT_SESSION の宿題リスト入り)
- 教訓: **位相検査は「整数ピッチ」と「中間位相」の両方を踏む** (1ピッチをN分割で走査)。整数位相だけの ✅ は
  近似プロファイルの罪を見逃す

## fix30: サロスリング回転符号の運動学的訂正 (fix22 の再訂正・パターン解読で確定)

- fix29/29b (歯幅・真ピッチ復帰) を当てても PAIR3 の中間位相⚠️が消えず、逆に増減 → 幾何でなく**位相式**を疑う
- 解読: 符号が逆なら位相ズレは 2·SAROS_RATIO·ca で蓄積し、**歯ピッチ4.865°の整数倍になる ca だけ偶然噛む**。
  実測 8角度の ✅/⚠️ がこの予言と **8/8 完全一致** (ca=14: 0.98ピッチ✅ / ca=7: 0.49⚠️ / ca=21: 1.46⚠️ /
  ca=28: 1.95✅ / ca=90: 6.27⚠️ / ca=100: 6.97✅ …) — 決定的証拠
- 原理: **内歯噛みは回転方向を保存する** (遊星→内歯36 と同じ標準則)。アイドラ(−)→サロスリングは(−)。
  PAIR2 (かご/リング46×アイドラ) 全緑 = アイドラ側の符号は正 → 反転すべきはサロス側のみ
- 教訓: **「どの角度が緑か」は情報である**。⚠️の分布が周期構造を持ったら、幾何より先に位相式の整合を疑う。
  fix22 (視覚検品による符号反転) は運動学の裏取りを欠いていた — 見た目の向きの正しさと式の整合は別検査
- ⚠️ 帰結: サロスの表示回転向きが fix22 承認時と逆転 — **検品17 (たまさん判定) 待ち**。教義上の正しい向き
  (「223の環」をどちら向きに読むか) は意匠判断のため機構検証では決められない
- fix29b (真ピッチ・歯先54.4・壁56.8) は独立に正当 (共役と逃げの回復) のため維持

# 検品17「サロスの回転向き (fix30後)」判定 (2026-08-14 夜)

**判定: このままで承認** (たまさん)。上から見て本体反時計回りのときサロス時計回り = fix30 の機構整合の向きを正とする。
アイドラ2段化による反転改造は不要。fix22 の視覚判断は「式の不整合が生む見かけ」への対症だったと結論。

---

# v0.6b 歳差の自動駆動 — 地下輪列 (2026-08-14 深夜)

## 実装

- 上ルートは柱+スタッドの**歳差掃引壁** (z3-17, r11-19.5) で不成立 (fix25 の教訓の再演) → **ベース裏 z-3.9〜-0.9 の平面列**
- 軸8T→W1 78T→(P1 8T→I 10T→)W2 78T→縦シャフト (r24.5 貫通)→提灯6ピン→**冠環43T (ターンテーブル上 z3-5)**
- 総減速 **1/681.3** (目標 684=228×3・誤差 -0.4%・考証1%内)。符号4回反転で逆行 ✓。pa は ca 従属化 (AUTO_PREC)
- 噛合位相は **mesh_phase() 解析解**を新設 (歯↔溝の転写式) — 夜行軍バッチで PAIR11 が 0.001mm³ 級 = 解析解が命中。
  手動位相チューニング (fix16 以来の文化) からの卒業第一号

## fix31: 小歯数アンダーカット + ピン過太 (夜行軍バッチの検出)

- PAIR12/13 (8T×10T / 10T×78T): 全角度 0.35-0.64mm³ の**一定値**擦り — 位相パターンなし = プロファイル問題。
  20°圧力角の8-10枚歯はアンダーカット限界以下 (インボリュート部が痩せる) の定番干渉
- PAIR14 (提灯×冠環): **ピン d1.8 > m1 歯溝 1.57** — ピンが溝より太い設計ミス。対称パターン (ピッチ内位置依存) が裏付け
- 対策: ①地下輪列の軸間 **+0.15 バックラッシ** (21.5→21.65 / 4.5→4.65 / 22→22.15) ②ピン d1.8→**1.6**
  ③冠環を **offset -0.3 シェービング** (歯厚1.57→0.97 — 薄歯はサロス文化の実績内・歳差駆動はトルク極小)
- 教訓: **「全角度で一定の⚠️」はプロファイル、「周期的な⚠️」は位相** — fix30 と対になる診断規則

## fix31b: スタブ歯 (アデンダム係数 ak) — 小歯数アンダーカットの根治

- +0.15 軸間バックラッシ (fix31) では PAIR12/13 の 0.44-0.52mm³ が不動 → **相手歯先が基礎円より深く
  突っ込む非共役 (トロコイド) 干渉**と確定。遊びでなく歯先の「届く深さ」の問題
- 対策: gear2d に **ak (アデンダム係数)** を追加し、歯先を相手の基礎円手前で止める:
  P1 ak0.6 (歯先2.3 < I基礎円2.349) / I ak0.5 (2.75 < P1側到達1.9≧基礎円1.879) / W2 ak0.6 (19.8)
- 副作用: 作動歯たけが薄く**遊び大きめ** (接触比ぎりぎり)。歳差駆動はトルク極小・一方向連続回転なので許容。
  実機で渋い/飛ぶ場合は**軸間シムで +0.15 を詰める**調整代を残してある (吊りスタッドは接着前に現物合わせ可)
- 教訓: 8-10枚歯 (20°圧力角のアンダーカット限界17枚以下) を使うときは最初からスタブ歯で設計する

## v0.6b 最終判定 (2026-08-14 22:40)

- PAIR11 ✅ / **PAIR12・13 = 0.10-0.23mm³ で受容** (PAIR5 の受容済み 0.15-0.24mm³ と同級。機械内最小トルク部・
  ゼロ追求は作動歯たけ=接触比を失う悪トレード。実機調整代 = 吊りスタッド接着前の軸間シム) / PAIR14 ✅ /
  collide 4方位 ✅ / collide_prec 4方位 ✅
- **v0.6b 実装・検証完了**。受容かすり台帳 (悪化してなければOK): PAIR4 0.001 / PAIR5 0.15-0.24 /
  PAIR6 6.1-6.7 / **PAIR12 ≤0.23 / PAIR13 ≤0.20**

## fix32: 印刷分割の刷新 (v0.6c, 2026-08-15)

- 旧切り線 az60 が v0.6b の裏スタッド (S1 az60.0 / SI az61.4) を**直撃** → 切り線 **48/168/288** へ
  (全フィーチャー方位を列挙検算・最小クリア 2.5° = az288 vs st1スタッド285.5)
- 切り楔を z-20 起点に (旧 z0 起点では裏スタッドがどのセグにも含まれず消失)
- 継ぎ板は土手 (v0.6a・全周壁) が旧座 r28-42 を潰したため **r23.4-29.4** (浅皿と土手の間) へ縮小移設 (6×8×2)
- 教訓: **分割線は「切る時点の全フィーチャー方位表」を作ってから引く**。版が進むと昔の空き方位は埋まる

## fix33: 8T は φ3 軸に住めない — 地下輪列を「14T→64T ×3段」に再設計 (v0.6c, 2026-08-15)

- STL シェル検査で **ub_pinionA がシェル8** = 8枚の歯が孤島。8T m0.5 の歯底円 r1.375 <
  圧入穴 r1.425 — **穴が歯車の胴を食い尽くしていた** (設計時に bore と歯底の照合を怠った)
- φ3軸/スタッド (穴1.425-1.7) に必要な歯底壁 ≥0.9 → **m0.5 の最小歯数 ≈ 13-14T**。
  ピニオン14T縛りだと2段で総減速95が稼げない (最大 ~6²=36) → **3段化**
- 新輪列: 軸14T→W1 64 / P1 14→W2 64 / P2 14→W3 64 (縦シャフト) → 提灯6→冠環43。
  総減速 = (32/7)³·43/6 = **684.66 (誤差+0.10% — 歴代最良)** ← ⚠️ fix36 (2026-09-28) で訂正: これは設計目標228との比較で、しかも遊星段の連成を落としていた。天文に対する真値は −1.37%。3段+提灯で符号4反転 → **アイドラ廃止**
- 玉突き: モータープレート 1mm 下げ (層 z-4.9..-1.0)・真鍮中心軸 31→32mm・M3 8→10mm・
  スタブ歯不要化 (14T は基礎円が浅くアンダーカット干渉が消える — fix31b の悩みも同時解消)
- 教訓: **歯車を軸に載せる前に「歯底円 > 穴半径 + 壁0.9」を検算する**。シェル検査は設計ミスの
  最後の網 (孤島の歯 = 8シェルが即座に教えてくれた)

## fix32b: ビルド域判定は「収まる回転の存在」で

- base_seg 回転判定で「最大寸法最小化」を目的関数にした結果 90.6×90.6 と誤判定 →
  正: **回転を掃引して (長辺≤133 かつ 短辺≤75) を満たす角があるか**。3セグとも 118.6×71.6 で収まる

## v0.6c 最終判定 (2026-08-15 15:20)

- fix33 (3段化) + W側 ak0.7 スタブ + 軸間 +0.25 の結果: **P12・P14 完全ゼロ / collide ✅ / シェル全✅**
- **P11 = 0.12-0.14mm³ / P13 = 0.22-0.26mm³ で受容** (PAIR5 級・ポリゴン近似粒度。機械内最小トルク部・
  吊りスタッド接着前の軸間シム調整代あり)
- 受容かすり台帳 (最終): PAIR4 0.001 / PAIR5 0.15-0.24 / PAIR6 6.1-6.7 / **PAIR11 ≤0.14 / PAIR13 ≤0.26**
- **v0.6c 完了** — STL 33ファイル (シェル+回転考慮ビルド域 全✅)・BOM v0.6c・ESP32 3:1・v4 バックポート済

---

# v0.7-A 銘と意匠 (2026-08-16 たまさん選定)

- **案1「考証オマージュ」採用**: ベース裏 (z0面・深0.8・帯r40-65) に円弧刻印 —
  上「ΜΗΧΑΝΗ ΟΥΡΑΝΟΥ (天の機械)」/ 下「ΣΕΛΗΝΗ · ΣΑΡΟΣ · ΜΕΤΑΠΤΩΣΙΣ (月・サロス・歳差)」/
  右「MMXXVI」/ 左「巡る天の心臓」。コイン様式 (下弧は flip で正立読み)。案2/3 は ENGRAVE=2/3 で比較残置
- **かご意匠**: 台座上面 r31.3-34.3 に雷文 (メアンダー) 24連・深0.5 — ギリシャ銘と意匠統一
- 検証: 刻印は両方とも既存体からの**減算のみ** → collide/bite 成績は不変 (回転体・固定体とも縮小方向)。
  シェルのみ再検査 (base_seg×3 / cage_core)
- 道中1匹: cage_core 編集で difference の閉じ括弧を落とし parser error (EOF到達) — 括弧カウンタで即特定

## fix34: 縦シャフト通し穴の座標リネーム事故 (v0.7-A のシェル検査が捕捉)

- base_seg2 シェル=2 → 分離片の座標特定 (z[-3.7,-1]・r26-29・az41-47) = **W2P2スタッドの切断された根本**
- 原因: fix33 の座標リネーム (旧S2=縦シャフト → 新S3) の際、base() の通し穴だけ S2_XY のまま残存 —
  ①穴がW2P2スタッド (d3 < 穴3.6) を z-1 以上で貫通消滅させ ②本来の S3 (24.5,0) に穴が無い
- collide では見えない盲点 (穴もシャフトも fixed 側同士 = 交差検査されない)。**シェル検査だけが見える網** —
  fix33 (8Tの孤島) に続き2匹目の大物
- 教訓: **座標定数をリネームしたら全使用箇所を grep で数え合わせる** (追加した箇所数と置換した箇所数の照合)

---

# v0.7-D 隣接台帳監査 (2026-08-17) — engage 検査体系の新設

たまさん発注「全構造物の隣接噛合関係と接触物が、あるべき位置にちゃんとあるか判定して」への回答。

## 新設: engage 検査 (PART="engage", EP1-15)

- collide (ぶつからない)・bite (噛み込まない) は**不在バグに盲目** (fix34 が証明) → 逆向きの
  「**寄せたら必ず重なる = ちゃんと触れている**」検査を機能噛合15ペア全数に新設
- 結果: **15/15 ✅** (体積 0.03〜51.6mm³ — 接触の実在を機械的に証明)
- 教訓: **engage の寄せ方向は「動力が流れる向き」** — ピン×溝は接線 (半径寄せだと溝底非接触=仕様が偽⚠️になる。
  EP13 初版で自ら踏んだ)

## fix35: ジャーナル2穴の締め直し (監査の戦果)

- はめあい全数再計算 (25件) で検出: 縦シャフト×ベース穴・中心軸×床穴が**通し径3.6のまま (+0.6ガタ)**。
  縦シャフトは提灯×冠環の軸受で、0.6のガタは噛み深さ ~1mm を食い潰す恐れ → **標準ジャーナル3.4へ統一**
- 背骨 bore 3.6 は意図的に残す (ターンテーブルは軸と別速度で回る逃げ穴)
- BOM 訂正: 「冠傘圧入」→ 実際は すきま0.15+瞬着 (v0.2以来の意図通り・表記のみ修正)
- 台帳: adjacency-ledger-v6.html (噛合15+接触25=40関係・全✅)

---

# v0.7.1 Opus 5.5 全体見直しの戦果 (2026-09-28) — 数字の主張・月時計・PAIR6

経緯: review-2026-09-28_opus55.md。たまさん「Opus5.5が来たので全体を見直して」→ 3番 (全部盛り) を選択。

## fix36: 交点歳差の「誤差 +0.10%」は誤り → 最終段 65T で +0.18%

- 遊星段の式 ω_軸 = 4ω_tt − 3ω_リング に地下輪列 ω_tt = ω_軸/PR を入れると、**歳差1周 = リング (PR−4)/3 回**。
  旧記述は PR/3 = 228.2 を設計目標 228 と比べて +0.10% としていた。二重の誤り:
  (a) 比較相手のすり替え — v6-design.md の「1/228 (誤差1%)」という正直な注記が、fix33 で目標とよく合った時に
  「天文との誤差」として書き直された (b) fix25 で自分で書いた「0.6%の結合」項を、比の計算で落とした
- 真値: 旧設計 226.89 朔望月 vs 天文 230.05 (交点周期 6793.5日 = 交点月と恒星月から算出) → **−1.37%**
- 対策: W3 だけ 64T→**65T** (軸間 20.00)。S2 を一般の円交点に書き換え、S3 (縦シャフト) は不動。
  PR = 695.35 → **230.45 朔望月 (+0.18%)**。アニメの歳差角も連成込みの厳密式 −3ca/(PR−4) に
- 掲載16ファイル (公開サイト含む) を訂正。公開物には訂正文を残した (黙って書き換えない)
- **教訓: 「何と比べた誤差か」は数字を載せるたびに引き直す**。collide/bite/シェル/engage はどれも幾何の網で、
  主張の出典は見ない — 五つ目の検査は「主張の再計算」

## fix37: PAIR6 (天球提灯×冠歯90) の噛み込み 6.7mm³ を設計で解消 → 最悪 0.26mm³

- 当初の仮説「傾いた歯に対してピンが斜めに横切る」はせん断実験で否定 (どちら向きでも悪化)。仮説を捨てて塊を解剖:
  ①**傾いた歯先がピン台座 (ハブ上面 z22.8) に刺さる** (最大 — 23.4° の傾きでハブ幅10.5の間に歯先高さが~2mm変わる)
  ②ピン先端が天球リング底に0.2刺さる ③④ピン側面×歯側面
- 対策: ハブ上面を1.8下げてピンを下へ延長・ピン先端を1.2詰め (z24.9)・ピン径 2.2→1.8・冠歯を台形 (根元1.3→先端0.5)
- 8位相スイープ: 最悪 0.263mm³ (95%減)・engage EP7 = 0.339 (噛み合い実在)。受容台帳の PAIR13 級
- 教訓: **受容した残差は「なぜ残るか」を解剖するまで受容しない** — 6mm³ は「歯当たり調整で吸収」できる量ではなかった

## fix38: ESP32 月時計の 0.59% 遅れ

- `STEPS_PER_CAGE_REV = 4096×3` は fix36 と同じ連成を無視 → 月4.2時間・年2.1日の遅れ。「整数なので累積誤差ゼロ」表記も誤り
- 対策: 4096 × 3 × PR/(PR−4) ≈ 12359.1 (double 保持)。lunar の1ステップ ≈ 206.4 s

## 検証基盤: Manifold バックエンド (約100倍速)

- `openscad --backend=Manifold` は CGAL と同体積 (PAIR6 6.124mm³ で一致) を約1秒で返す → 全数検証が数分に
- ただし**設計どおり面で載る座面** (リング46溝天井×土手上端 z10.5) を厚さ0.01mm の薄膜として出力する (CGAL は空)。
  `stl_solid.py` で最小寸法 <0.02mm の成分を「座面の接触」として別勘定にする
- 全数検証台本: `verify_v7.sh`

## v0.7.1 全数検証 (Manifold・実体積)

| 検査 | 結果 |
|---|---|
| collide 8角度 / collide_sun 16方位 / collide_prec 8方位 | 全 0 (座面薄膜 2.67 は別勘定) |
| PAIR2/3/7/8/9/10/14 | 全 0 |
| PAIR4 / PAIR5 / PAIR6 / PAIR11 / PAIR12 / PAIR13 | ≦0.001 / ≦0.28 / ≦0.26 / ≦0.14 / ≦0.05 / ≦0.14 |
| engage EP1-15 | 全て非空 (0.03〜51.6) |
| シェル (形が変わった8部品) | 全て 1 |

受容台帳 (最終): PAIR4 0.001 / PAIR5 0.28 (ca25 は変更前から同値 — 今回初めて踏んだ位相) / PAIR6 0.26 / PAIR11 0.14 / PAIR12 0.05 / PAIR13 0.14

---

# v0.7.2 物理チェックの戦果 (2026-09-28) — 重力と総当たり

経緯: physics-check-2026-09-28.md。たまさん「物理チェックまでいこー」→「1 (機械の修正を一式)」。
力 (トルク余裕14倍・浮きなし) は問題なし。問題は**高さの取り合い**と**重力の支え**に集中していた。

## 新しい網: 総当たり (五つ目) と重力 (六つ目) — `pairwise.scad` / `pairwise.sh`

- **総当たり**: 17剛体の全ペア × 角度。collide は「回るもの×固定物」、bite は「噛み合う相手」だけを見るので、
  **回るもの同士の非噛合**と**ベース×サロス環**が死角だった。サロス環はどの検査にも入っていなかった
- **重力**: 各剛体を 0.3 下げ、噛み合う相手以外と交わるか = 下で何かが受けているか。
  **CAD の中の部品は宙に浮いていても回る**ので、支えの有無はこれでしか見えない
- 教訓: **高さを引き直したら、隣の住人を総当たりで確かめる**。**部品を置いたら、何が下で受けるかを確かめる**

## fix39: サロス環がベース板に 0.5 沈んでいた (2566mm³)
- v0.6a で H_SAROS 4→2.5 にした時、座の壁が板の中に埋没し、環の底 z2.5 が板の上面 z3 より下に → 板に座溝 (r54-69.5・深さ0.5)

## fix40: 地面の高さの引き直し (324 / 42mm³)
- v0.6a で st1 主輪・冠アイドラ下段は −3、サロス環は −1.5 下げた → 1.3 の重なり
- 冠アイドラを上下入れ替え (下段22T z9-13 / 上段11T z13.2-15.8)・st1 主輪を z13.2 へ (提灯ピンの空間高さは不変)
- さらに **st1 のスタッド (r53.5・d3) 自体が環の歯先 r54.4 に 0.6 食い込む位置を貫いていた** (v0.4b 以来) →
  ベースから立てるのをやめ、環の内側 (r50) の柱から環の上 (z7.8-8.8) を腕木で渡し、肩で受ける (st1_bracket)

## fix41: 支えの肩・太陽の下ハブ・地下の軸端キャップ (重力で落ちる部品6点)
- 遊星・冠アイドラ・st1・サロス中間輪: スタッドに肩 (d5) — 設計の高さで受ける
- 太陽: 下へハブ d6 を伸ばしターンテーブル上面で受ける (手回し時は中心軸ごと 6mm 落ちて遊星と外れていた)
- W1P1・W2P2: 吊りスタッドを延ばして軸端キャップ (stud_cap 流用・計5個に)

## fix42: 天球支柱 az215 がサロス環の歯先を 0.2 かすめていた → サロス帯 (z≤8.5) は d3.8 に細身化

## fix43: +x 側の遊星がスタッドに入らない → 傾斜プレートの局所 x>4.9 を切り欠き
- 低い側の縁 (z13.7〜15.4) が遊星の真上に張り出していた。プレートの仕事 (かごの座・柱の受け・ボス) は切り欠き後も満たす
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

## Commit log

2026-08-18 initial: meguru — antikythera x tourbillon design record (scad, 33 STLs, docs site)
    [base_seg0.stl, base_seg1.stl, base_seg2.stl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]
2026-09-28 v0.7.1: correct nodal-precession claim (+0.10% was wrong, true -1.37%) -> 65T final stage gives +0.18%; PAIR6 interference 6.7->0.26 mm3; ESP32 coupling fix; Manifold verify script
    [base_seg0.stl, base_seg1.stl, base_seg2.stl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]
2026-09-28 README: known issue — physics check found assembly blockers, fix in progress
2026-09-28 v0.7.2: physics-check fixes (overlaps, gravity supports, D-cut drive, 3-point sky support) + all-pairs/gravity checks; stand & motor mount pending
    [base_seg0.stl, base_seg1.stl, base_seg2.stl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]
2026-09-28 physics_check.py: find STLs in stl/ (public repo layout) as well as stl_v6/
2026-09-28 v0.7.3: stand (armillary tripod + foot ring) and motor cradle
    - Stand B chosen by touchable comparison: 3 flared legs glued at the base rim (r68,
    clear of the engraved inscription) onto a 4-piece foot ring (r72-82)
    - Motor cradle hangs from two posts under the base, held by M3 thumb screws from below;
    it slides out to the front, so hand/motor swap needs no tools and never touches the mechanism
    - Coupling retired: the stepper's double-flat shaft slides into a slot under the hand knob
    - New check: swap path (swept removal vs everything, with negative controls);
    all-pairs/gravity extended to 20 bodies x hand/motor modes; engage EP16 for the slot
    - Tipping angle recomputed from the assembl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
    [base_seg0.stl, base_seg1.stl, base_seg2.stl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]
2026-09-28 docs: assembly guide stage 4 — slide-in illustration for the motor cradle
2026-10-13 docs: add the anatomy figure (anatomy-v7.html) as the 5th page — knob-driven, explodes by stage
2026-10-13 docs: anatomy figure — part descriptions wrap under the card instead of overflowing the readout corner
2026-10-13 docs: anatomy figure — description sits below the part buttons with reserved height; a chosen part stays selected until Escape
2026-10-13 docs: Fig 2 — the libration elliptical gears as a touchable figure (libration-v7.html); linked from the index and the 考証 table
2026-10-17 docs: new entrance page; the old index kept as index-classic.html
    The intro page from the taste-skill comparison becomes the site's front door.
    - Literata (Google Fonts) replaces Sentient for Latin text and the Greek
    inscription; Japanese stays in Noto Serif JP
    - phone: the four devices are one screen instead of a pinned 4.5-screen story,
    and the explainer index has no page screenshots (11,566 -> 7,007 px at 390 px)
    - the node dial is the turntable seen from above (crown ring teeth, a scale of
    one tick per year, the node needle) instead of a pie chart
    - assets resized and re-encoded (4.9 -> 2.2 MB); the fragment credits say they
    are cropped and darkened on the page (CC BY 4.0)
    - the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
2026-10-17 docs: the verification history has 48 fixes, not 45
    mesh-verification.md runs to fix48 (fix46-48 came with the stand and the
    motor cradle on 2026-09-28); README and the entrance page still said 45.
